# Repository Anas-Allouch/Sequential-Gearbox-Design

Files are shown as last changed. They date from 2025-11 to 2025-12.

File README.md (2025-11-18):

# Sequential Gearbox Design

This project presents the complete design and analysis of a 5-speed sequential gearbox for a rally car.

## Project Scope & Contents

This repository documents the **complete design and analysis process** of a 5-speed sequential gearbox.  
It includes all engineering calculations, modeling, and verification steps based on *Shigley’s Mechanical Engineering Design* and *Le Guide du Dessinateur Industriel (Chevalier)*.

### Main Components & Analyses
- **Gear Design:** module selection, face width, geometry factors, bending and contact stress verification.  
- **Input Shaft Design:** static and fatigue analysis, keyseat and retaining ring groove checks, stress concentration factors.  
- **Output Shaft Design:** torque and moment diagram analysis, critical section evaluation, fatigue and safety factors.  
- **Bearings:** selection, equivalent load calculation, and life estimation.  
- **Keys & Retaining Rings:** dimensioning and verification against shear and crushing.  
- **Housing & Alignment Considerations:** bearing seat fits, shaft shoulders, and axial positioning.  

> The goal is to provide a **complete, transparent, and educational mechanical design example** of a sequential gearbox, from concept to validated dimensions.

## Tools & References

### Software
- **SolidWorks:** 3D modeling of gears, shafts, and gearbox assembly.  
- **MATLAB:** analytical calculations, torque and moment diagrams, fatigue and stress analysis automation.  
- **AutoCAD:** creation of final 2D technical drawings and detailed dimensioning sheets.  
- **Excel:** tabulated design data, safety factor summaries, and calculation sheets.

### References
- *Shigley’s Mechanical Engineering Design* — design methodology, fatigue and stress concentration analysis.  
- *Guide du Dessinateur Industriel (Chevalier)* — dimensional standards, tolerances, and technical drawing practices.  
- *Machinery’s Handbook* — complementary reference for mechanical design data and standard dimensions.

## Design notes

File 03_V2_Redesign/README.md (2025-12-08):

# Abandoning Initial Design (V1)
The first design (V1) was fully modeled and analyzed, but it reached a point where several key issues had no realistic or robust solutions within the existing architecture. Despite multiple refinements, the combination of geometric constraints, stress concentrations, assembly limitations, and interface problems (keys, dogs, shaft transitions, etc.) made it clear that continuing to iterate on the same base layout would not lead to a clean or reliable final design.  
For this reason, the V1 gearbox was OFFICIALLY ditched, and the project is now restarting from a fresh architecture (V2) in order to implement all lessons learned and integrate better design rules from the beginning.

---

# About This Folder (V2)

This folder contains the **new redesign workflow**.
The V2 design is documented through a dedicated Markdown file that records:

- the restart of the architecture
- the sequence of design decisions
- intermediate sketches and reasoning
- constraints and fixes applied
- and how the new gearbox layout evolves step by step

This approach keeps the development traceable and transparent until the final consolidated report is produced.

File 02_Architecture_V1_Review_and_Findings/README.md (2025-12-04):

# Architecture V1 - Review and Findings
This folder documents the **first complete gearbox architecture** of the project, including:
- Input shaft
- Output shaft
- Full set of SolidWorks gearbox parts used in V1
- The complete V1 gearbox assembly
- Initial dog–gear engagement concept
- Notes and explanations of the limitations discovered in this version

During the evaluation of this version, several **critical limitations** were identified.
These limitations led to the upcoming redesign.

### **01_Shafts_Drawings/**
Contains the exported shapes/representations of:
- **Input shaft**
- **Output shaft**

These are not final technical drawings, but the **geometric form and layout** of the shafts as designed in Architecture V1.
They are included here to document the original shaft concepts before the redesign and to allow easy comparison with V2 once all dimensions and calculations are finalized.

### **02_Gearbox_Parts/**
Contains all SolidWorks **individual gearbox components** used in V1:
- Output shaft
- Input shaft
- Gears
- Dog rings
- Keys
- Bearings

This allows reconstruction of the complete V1 assembly for reference.

### **03_Gearbox_Assembly/**
Contains the **Architecture V1 gearbox assembly**.

This assembly was created to:
- Visualize the overall concept  
- Check the positioning of gears, shafts, and dog rings  
- Verify clearances and relative spacing  
- Validate how the parts interact in 3D  
- Identify problems or design conflicts that were not obvious during individual part modeling  

Although this assembly contains limitations that led to the redesign, it is preserved here to document the initial idea and to compare it later with the improved V2 architecture.
In addition to verifying geometry, this assembly was also created to **step away from pure numbers and calculations** and actually build the concept in CAD, helping reveal issues that were not obvious on paper.

### **04_MATLAB/**
Contains the MATLAB work used during the Architecture V1 review.
#### **modified_scripts/**
#### **new_scripts/**

### **05_Safety_Factors_V1/**
Contains a table representing the safety factors that were calculated and resulted in a failed design.
It does not contain the equations and calculation details, but the results and some dimensions used.
it shows the failure points and some notes.

## Summary of V1 Findings

### **Key issues identified:**

1. **Output shaft keyseat depth too large** (7 mm on Ø50 mm shaft)  
   This leads to excessive radius removal → high Kt → fatigue risk

2. **Keyseat placed too close to a shoulder / critical section**  
   This creats a combination of stress concentrations (shoulder + keyseat) that severely weakens the shaft in bending and torsion

3. **Key failure risk on the output shaft**  
   Safety factors were only around **1.0–1.1** in shear and crushing, while the target is **1.5+**
   This makes the keyed dog-hub connection unacceptable on the high-torque output shaft, especially on the first gear

4. **Splines not feasible due to assembly and bearing constraints**  
   Needle bearings and stepped diameters prevent placing splines in the required locations
   Splines cannot be added “anywhere” making a splined dog hub impossible in this current version

5. **Dog ring requires a splined zone to slide axially**  
   For proper engagement into dog pockets, the dog ring must slide along a spline
   The V1 architecture did not provide any feasible spline region for this movement, blocking correct dog operation

## What I Learned
- Critical shaft features must always be checked for **combined stress concentrations**, especially when multiple geometric changes (shoulders, keyseats, grooves) are close together
- Dog hubs require careful balance between key depth, shaft diameter, and torque levels
- Needle bearings strongly restrict where splines can be placed
- Manufacturing feasibility and assembly constraints must always be checked throughout the design
- Initial designs rarely work perfectly — redesign is normal and often unavoidable

## Technical Skills Gained
- Involute gear tooth design
- Spline calculation and spline design
- Real dog-clutch concept understanding (engagement, load transfer, geometry)
- Designing all gearbox parts in SolidWorks (full parts + complete V1 assembly)

## Why I Made This Folder
- To document the first complete gearbox architecture (V1), even though the design ultimately proved unviable
- To clearly show the full concept assembly and the work completed before identifying its limitations
- To demonstrate my SolidWorks modeling skills through fully created parts and assemblies
- To validate the design visually in 3D and step beyond purely analytical calculations
- To identify problems that are not visible in numerical analysis alone, such as assembly feasibility, mounting constraints, and geometric conflicts
- To keep a transparent record of the shortcomings discovered in Architecture V1 before transitioning to a corrected and improved design

## Next Step
- Begin redesigning the output shaft to address the keyseat, stress concentration, and assembly issues identified in V1
- Rebuild the dog-hub interface with improved geometry and safer torque transmission
- Ensure that the new design achieves the desired safety factors (≥ 1.5) for all torque-transmitting features
- Validate whether modifying only the output shaft is sufficient to resolve the limitations
- If required, extend the redesign to include both the input and output shafts
- Integrate all lessons learned from V1 regarding splines, keys, dog engagement, manufacturability, and assembly feasibility
- Develop Architecture V2 as a corrected and more robust version of the gearbox design

## Important Note
Regarding the equations used, simplifications, asumptions and all details, they won't be shown until the final report is done.
This report will be done once everything is checked, and the design is acceptable, meaning no failure at at any point in the whole gearbox.

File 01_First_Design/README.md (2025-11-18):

# First Acceptable Design

This folder contains the first **acceptable and technically coherent**
design of the sequential gearbox project. It was created after multiple 
early design attempts that revealed significant issues, missing
information, or incorrect assumptions. These early failures were essential
for building a solid understanding of the constraints and requirements of
a real multi-speed gearbox.

Throughout the process, I encountered and learned numerous new concepts
related to gearbox engineering that do not appear in simple single-stage
reducers. Topics such as gear load distribution, shaft fatigue under
combined loading, bearing life calculations, and moment/torque diagrams 
were progressively integrated and refined as I
identified mistakes in previous versions.

This directory therefore serves as:
- a **checkpoint** for the first design that no longer contains major
  conceptual errors or unrealistic assumptions, and  
- a **trace of my progress**, documenting how the project evolved from
  failed early designs into a structured, technically valid gearbox
  model.

## Notes on Excel Tables

The Excel files in `02_Excel_Calculations` are **raw engineering 
worksheets**, not formatted reports. They store:
- intermediate values used by MATLAB scripts,
- extracted forces and geometries,
- safety factors calculated using MATLAB,
- and other working data.

Their purpose is to support calculations, not to present final, polished
tables. Clean, validated versions of these data sets will be produced in a
later stage once the full design is refined.

## Notes on CAD Models
SolidWorks part models and technical drawings are **not yet finalized**.
They will be developed once all dimensions, stresses, safety factors, and
design decisions are fully validated. The current `03_Shaft_Drawings`
folder contains only preliminary, non-refined versions of the input and
output shafts. Final CAD models and detailed drawings will be added in a
later design stage.

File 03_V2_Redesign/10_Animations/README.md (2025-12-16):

## Animations
This folder contains short animations of the sequential gearbox.
Each animation shows a single operating case, with one gear engaged at a time.

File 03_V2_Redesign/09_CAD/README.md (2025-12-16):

## CAD Models
Inside solidworks folder, you will find the assemblies, parts and bearings used.  
Two assemblies of the whole gearbox exist:  
- "Sequential_Gearbox": contains the original assembly
- "Sequential_Gearbox_Animation": contains multiple configurations and motion studies. Basically a configuration for each gear engaged alone.

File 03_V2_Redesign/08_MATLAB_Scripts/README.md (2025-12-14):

These MATLAB scripts were developed for preliminary sizing and iterative verification during the design process.  
They are not final or production-level scripts and may be refined or replaced in later design stages.

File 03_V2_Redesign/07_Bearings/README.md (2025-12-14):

# Bearings – Selection and Life Check

Bearings are selected and verified based on required life, reliability, and operating
loads. Life calculations follow standard rolling bearing theory.

---

## Design Targets

- Bearing life: L10,req = 667 hours  
- Reliability: R = 90 %
- Shaft speed range: 4000 rpm for all gears  
- Bearing type: Cylindrical roller bearings  

---

## Load Definition

Bearing loads depend on the engaged gear and transmitted torque.
Each gear produces a different bearing load.

---

## Time Fraction Method

Bearing life is evaluated using a duty cycle approach.

For each gear i:
- Time fraction: t_i  
- Equivalent bearing load: P_i
- Average Rotation Speed: n_avg,i

A global equivalent load is calculated using:

P_eq = [ Σ (t_i * P_i^p *n_avg,i) / (Σ (t_i * n_avg,i) ]^(1/p)

where: 
- p = 10/3 (cylindrical roller bearings)

---

## Results
After calucaltion, I got:
 - input shaft: C10 = 43.788 KN
 - output shaft: C10 = 38.215 KN

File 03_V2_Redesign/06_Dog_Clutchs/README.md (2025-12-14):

## Dog Clutch Failure Checks

Dog clutches are checked against crushing failure of the dog faces and shear failure of the dogs.
Torque transmission is assumed to occur through face contact between engaged dogs.

---

### 1. Tangential Force at Dog Radius

The transmitted torque T produces a tangential force at the mean dog radius:

Ft = T / r_m

where r_m is the mean radius of the dog engagement.

---

### 2. Crushing Failure of Dog Faces

The average bearing (crushing) stress on the engaged dog faces is:

σ_c = Ft / (N_e * A_d)

where:
- A_d is contact area of one dog  
- N_e is the effective number of dogs carrying load

The crushing safety factor is:

n_crushing = σ_c,allow / σ_c

where:
 - σ_c,allow = 0.6 * S_y  

---

### 3. Shear Failure of Dogs

Each dog is also checked in shear at its root section.

The average shear stress in one dog is:

τ = Ft / (N_e * A_s)

where:
- A_s is the shear area of one dog (root cross-section)

The shear safety factor is:

n_shear = τ_allow / τ

where:
 - τ_allow = 0.3 * S_y  

---

### Assumptions

- Load is shared by a limited number of dogs due to manufacturing tolerances  
- Contact pressure is uniformly distributed over the engaged dog faces  
- Dynamic and impact effects during engagement are neglected  
- Dogs are fully engaged during torque transmission  
- Material yield governs failure (fatigue not considered here)

---

### Notes

- Dog clutches are primarily torque-locking elements, not synchronizing devices  
- Impact loads during shifting can govern design in high-speed applications  
- Face width and dog count strongly influence durability and engagement quality

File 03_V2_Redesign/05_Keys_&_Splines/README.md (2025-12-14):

## Key Safety Factor Checks
When dealing with keys, there are 2 types of failures: failure by shear, and failure by crushing.  
Since im using custom made keys, and not using the same key everywhere, safety factor check is required at every key location.  
In the following, i will show the formulas used to calculate these safety factors:  

### 1. Shear Failure Check

The transmitted torque T produces a tangential force on the key:

Ft = 2 * T / d

The average shear stress in the key is:

τ = Ft / (b * l)  

with b: key width;  
     l: key length

The shear safety factor is:

n_shear = τ_allow / τ  

τ_allow = 0.3 * S_y  

where the allowable shear stress is taken from the key material yield strength.

---

### 2. Crushing Failure Check

The same tangential force produces a bearing pressure between the key and the hub.

The average crushing stress is:

σ_c = Ft / (h * l)  

with h: contact height between key and shaft, or key and hub ( both must be checked )  

The crushing safety factor is:

n_crushing = σ_c,allow / σ_c  

σ_c,allow = 0.6 * S_y

---

## Spline Failure Checks
Splines are checked against bearing (crushing) failure of the spline teeth.  
Shear of spline teeth is generally not governing and is neglected in standard design practice.  

---

### 1. Tangential Force at Spline Radius

The transmitted torque T produces a tangential force at the spline radius:

Ft = T / r

where r is the pitch circle spline radius.

---

### 2. Crushing Stress on Spline Teeth

The average crushing stress on the loaded spline flanks is:

σ_c = Ft / (N_e * h_e * l)

where the effective number of teeth in contact is:

N_e = 0.3 * N  

And h_e is the height of the tooth ( distance from addendum to dedendum )  

---

### 3. Crushing Safety Factor

The crushing safety factor is defined as:

n_crushing = σ_c,allow / σ_c  

σ_c,allow = 0.6 * S_y  

where the allowable crushing stress is based on the yield strength of the weaker material  
(shaft spline or hub spline).

---

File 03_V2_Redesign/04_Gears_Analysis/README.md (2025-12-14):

# Gears Analysis
Based on Shigley ways and AGMA standards, there are 2 types of failures that can occur in gears: failure by bending, and failure by wear ( or contact ).  
In this folder, you will find a table showing the safety factor for each case, for every gear in the gearbox.  
As always, assumptions and constants are going to be mentioned in the final project report.  

Values are calculated with the MATLAB code that can be found in its corresponding folder.

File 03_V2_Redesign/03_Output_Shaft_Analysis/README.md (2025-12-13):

For the output shaft analysis, we will be using the same moment diagrams used for input shaft.  
The reason why I let myself do that is because the axial positions of gears, where forces are applied, is the same as on the input shaft.  
The difference is that the forces are in the opposite direction shown on the input shaft, excluding reverse gear.  
The real moments diagrams on the output shaft are flipped in comparison to input shaft diagrams, but the absolute value of moments is always the same, so technically we can use the same moment diagrams cause it will not affect calculations.  
So each pair of gears, I took the one that is more critical and gives higher moment values and I calculated the safety factors based on it. 
These pairs are grouped like the following:  
 - Reverse gear with gear 1  
 - Gear 2 with gear 3  
 - Gear 4 with gear 5  

So for the first pair, I used the gear 1 moment diagrams. For second pair, I used the gear 2 moment diagrams. For the third pair, I used the gear 4 moment diagrams.  
And each pair has a dog clutch mecanisme between them.

Same as input shaft, an excel table includes all safety factors of different shaft fatigue analysis criterias.

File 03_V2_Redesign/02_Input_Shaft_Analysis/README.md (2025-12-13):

This folder presents input shaft analysis. From free body diagram, to moment diagrams for each case that we have, to finally fatigue analysis.  
Regarding fatigue analysis, I used all 4 different criterias that Shigley had in his book. However, the important safety factor that I will be using as my reference
safety factor is Goodman.  
In some places, ASME elliptic criteria might produce low values, and that's completely normal when the moment values at that location are low. And that weird behavior is one of the reasons why Goodman is the criteria to follow since it is conservative in all cases.  
The calculations and formulas details will not be shown until the final polished report.  
An excel table in "Shaft_Analysis" folder contains the different safety factors at each shaft feature ( shoulders, grooves, keyways, ... )  

Calculations were done with the help of the matlab code that can be found in 08_MATLAB_Scripts in its dedicated folder.

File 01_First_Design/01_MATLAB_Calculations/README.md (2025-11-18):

# MATLAB Calculations (Initial Design Phase)

This directory contains the MATLAB modules used during the first design
of the sequential gearbox project. Each sub-folder corresponds
to a specific analysis task (gear forces, moment diagrams, shaft stresses, etc.).

The scripts and functions here are **not optimized** and **not intended
for production-level code**. Their purpose is only to automate repetitive
engineering calculations and avoid doing them manually in Excel.

## Structure
Each module folder contains:
- A main script (`*_main.m`) that runs the calculation.
- Local helper functions used by that module.
- Path setup at the top of every script to correctly access Excel data
  stored in `02_Excel_Tables`.

## Notes
- All paths to Excel files are handled dynamically using
  `mfilename('fullpath')` to ensure compatibility on any computer or
  GitHub clone.
- No global code organization or optimization has been applied yet.
- A future “clean code” pass will reorganize, optimize, and document the
  final version of the computational tools.

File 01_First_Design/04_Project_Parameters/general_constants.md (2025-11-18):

# General Design Constants

## Gear Geometry

- **Gear type:** Spur gears  
- **Module:** 3.5 mm/tooth
- **Face width, b:** 35 mm  
- **Pressure angle, α:** 20°  

These values are taken as fixed for all gears in this first design 
and are used consistently in gear, shaft, and bearing calculations.

## Components

- **Keys:**  
  - Custom dimensions (non-standard).  
  - Sized specifically for the shaft diameters and torque levels in this
    gearbox rather than using catalog key sizes.

- **Bearings:**  
  - Standard catalog bearings are used.  
  - Selection is based on load capacity and life (L10) according to
    manufacturer data.

- **Retaining rings:**  
  - Standard (catalog) retaining rings.  
  - Grooves and shoulder details follow standard recommendations for
    the chosen ring series.

## Design Scope

These constants define the baseline configuration for the first complete
acceptable gearbox design. Any change to module, face width, pressure
angle, or component standardization would require a global redesign of
gears, shafts, and associated components.

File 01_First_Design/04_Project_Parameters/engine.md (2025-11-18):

# Engine and Input Torque Assumptions

## Intended Application

The gearbox is not designed for a specific competition homologated rally car,
but for a **rally-style/off-road oriented car** built with high torque and
good drivability in mind. The goal is to size a sequential gearbox capable of
handling realistic loads for a powerful off-road/rally-style vehicle, without
being tied to an exact commercial engine model.

## Engine Performance Assumptions

For the purposes of gearbox design, the engine is assumed to deliver:

- **Peak torque:** ≈ 450 Nm  
- **Peak power:** ≈ 350 hp  

These values are representative of a highly tuned turbocharged engine
(4- or 6-cylinder) where:
- Maximum torque (~450 Nm) occurs at mid-range rpm, and  
- Maximum power (~350 hp) is reached at higher rpm.

Only the **torque** is directly used for gearbox sizing. Power is mainly
indicative, to ensure the chosen torque level is consistent with a realistic
engine configuration.

## Use in the Design

In this first design:
- The **450 Nm** torque level is taken as the reference **maximum engine
  torque at gearbox input** (before gear ratios).
- Safety factors, overload factors, and dynamic effects are handled in the
  subsequent gear, shaft, and bearing calculations, based on this input
  torque level.

A more detailed engine torque curve (torque vs rpm) may be introduced in a
later refinement stage if needed, but for now the design is based on this
single worst-case torque value.

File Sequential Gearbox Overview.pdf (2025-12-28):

Author: Anas ALLOUCH

## Sequential Gearbox

## Project Concept and Objectives

This project focuses on the complete mechanical design of a 5-speed sequential gearbox, developed as a self-driven engineering effort with the intention of approaching a realistic and manufacturable solution rather than a purely academic exercise. The gearbox architecture is based on dog-ring engagement mechanism, a configuration commonly found in high-performance and motorsport applications. A mechanism that operates through purely mechanical means.
Unlike conventional gear reducers or speed multipliers, which operate under fixed and well-defined conditions, a sequential gearbox inherently combines multiple operating cases within a single design. Each gear engagement represents a distinct load path and loading condition, affecting gears, shafts, bearings, splines, keys, and engagement components differently. A central challenge of this project was therefore to identify the most critical cases while ensuring overall coherence and consistency across the entire drivetrain.
The design was approached with a strong emphasis on classical mechanical engineering principles and established design standards. Component sizing and verification were performed using analytical methods drawn from machine design theory, bearing catalogs, and international standards, with careful attention paid to the assumptions underlying each calculation, their validity, and their impact on the final results.
Beyond obtaining numerical safety factors, the project aimed to develop a deeper understanding of how real mechanical systems are designed, including the need for iteration, trade-offs, and refinement. Multiple intermediate concepts and configurations were evaluated and ditched before obtaining the final design.

## Main Objectives

- Design a complete and coherent sequential gearbox architecture
- Integrate gears, shafts, bearings, splines, keys, and dog clutches into a single functional system
- Apply classical mechanical design theory to verify critical components
- Develop a design that serves as a basis for further tests and verification, taking it from analytical to experimental validation

L | L
K | K

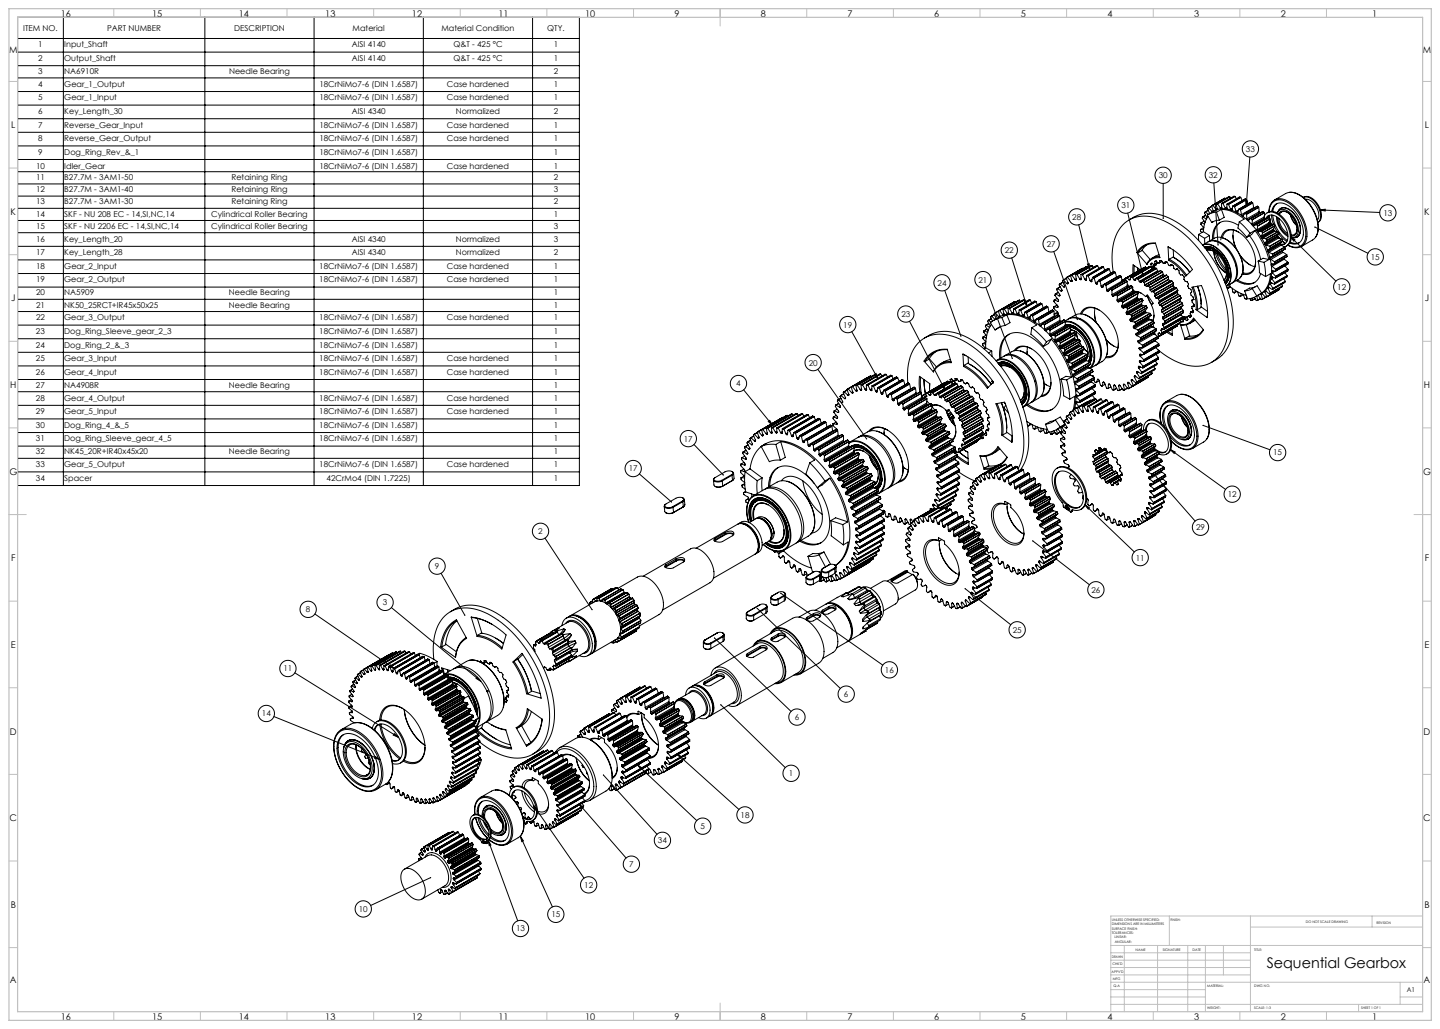
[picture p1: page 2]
ITEM NO.; PART NUMBER; DESCRIPTION; Material; Material Condition; QTY.; Input_Shaft; AISI 4140; Output_Shaft; Needle Bearing; Gear_1_Output; 18CrNiMo7-6 (DIN 1.6587); Case hardened; Gear_1_Input; Key_Length_30; AISI 4340; Normalized; Reverse_Gear_Input; Reverse_Gear_Output; Dog_Ring_Rev_&_1; Idler_Gear; Retaining Ring; SKF - NU 208 EC - 14,SI,NC,14; Cylindrical Roller Bearing; SKF - NU 2206 EC - 14,SI,NC,14; Key_Length_20; Key_Length_28; Gear_2_Input; Gear_2_Output; NK50_25RCT+IR45x50x25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

UNLESS OTHERWISE SPECIFIED:
DIMENSIONS ARE IN MILLIMETERS
SURFACE FINISH:
TOLERANCES:
LINEAR:
ANGULAR:

NAME | SIGNATURE | DATE | | | TITLE: Sequential Gearbox

DRAWN
CHK'D
APPV'D
MFG
Q.A | | | | MATERIAL: | DWG NO. | A1

## Verification and Engineering Work

The mechanical design of the sequential gearbox was verified using classical machine design methods and established engineering references. Gear geometry and strength were evaluated using AGMA-based criteria to ensure adequate resistance to bending and contact stresses under the most critical operating conditions.
Shafts were dimensioned and verified under combined torsional and bending loads. Stress concentration effects and fatigue behavior were evaluated using standard failure criteria as presented in Shigley’s Mechanical Engineering Design, allowing identification of governing sections and critical load cases.
Bearing selection was performed using the Shigley bearing life methodology, based on duty-cycle-dependent equivalent dynamic loads. Bearings were selected from manufacturer catalogs such that their basic dynamic load ratings exceed the calculated equivalent loads.
Torque transmission elements, including keys, splines, and dog clutches, were verified against their governing failure modes using classical strength-of-materials approaches. Keys were checked in shear and crushing, splines were verified in bearing pressure following standard practice, and dog clutches were evaluated for crushing and shear of the dog teeth.
The final design is the result of multiple iterations, during which several intermediate configurations were evaluated and refined. This process highlights the iterative nature of engineering design, where minor adjustments can sometimes resolve identified issues, while in other cases a more substantial redesign is required to achieve a satisfactory solution.

## What I Learned

This project provided a comprehensive learning experience in mechanical design, extending beyond isolated calculations to the development of a complete and coherent drivetrain system. One of the most significant lessons was learning how to define, justify, and apply engineering assumptions. Understanding when simplifications are valid, how they influence results, and how to interpret safety factors in context proved to be as important as the calculations themselves.
From a technical perspective, the project deepened my understanding of drivetrain components and their interaction within a complex mechanical system. Designing a sequential gearbox required integrating gears, shafts, bearings, splines, keys, and dog clutches into a single architecture, while accounting for multiple operating cases and distinct load paths. This differs fundamentally from the design of fixed-ratio reducers, where operating conditions are more limited and uniform.
In addition to technical knowledge, this work strengthened practical engineering skills related to design iteration and problem-solving. Several intermediate design concepts were analyzed and discarded as new constraints emerged, leading to progressive refinement of the gearbox layout and component sizing. This iterative process highlighted the non-linear nature of real engineering design.
From a software perspective, the project improved proficiency in CAD modeling, assembly management, and technical drawing preparation, as well as in the organization and documentation of complex engineering work. Structuring calculations, design choices, and results in a clear and traceable manner was a key outcome of the project.
Overall, this project reinforced the difference between theoretical coursework and practical mechanical design, providing a realistic view of the engineering process and significantly deepening both technical understanding and engineering judgment.

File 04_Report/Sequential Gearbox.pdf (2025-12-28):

## Engineering Design Study

## Sequential Gearbox

Mechanical Design Report
Personal Engineering Project

Author: Anas ALLOUCH

## Contents

1 Introduction | 4
2 Technical Specifications | 5
3 Gearbox Architecture and Layout | 7
4 Shaft Design and Verification | 9
5 Gears Analysis | 20
6 Keys | 24
7 Splines | 26

8 Bearings | 27
9 Engagement Mechanism | 29
10 Design Summary | 33
11 Design Assumptions and Limitations | 33
12 Supporting Material | 33
13 Conclusion | 34

## List of Tables

1 | Gear specifications and ratios | | 5
2 | Vehicle speed and wheel torque at redline (neng = 6500 rpm) | | 6
3 | Assumed time fraction per forward gear | | 6
4 | Summary of materials used for main gearbox components | | 7
5 | Bending moments and torsional loading at critical shaft features – Gear 1 engaged – input shaft . 14
6 | Bending moments and torsional loading at critical shaft features – Gear 1 engaged – output shaft 14
7 | Theoretical stress concentration factors for the input shaft | 18
8 | Theoretical stress concentration factors for the output shaft | 18
9 | Fatigue safety factors for the input shaft – Gear 1 engaged | 19
10 | Fatigue safety factors for the output shaft – Gear 1 load case | 19
11 | Summary of Gears Safety Factors | 24
12 | Safety Factors of Keyed Connections | 25
13 | Crushing Safety Factors of Spline Connections | 27
14 | Needle Bearings Used for Gear Support | 29
15 | Dog Ring Geometry and Safety Factors | 32

## 1 Introduction

### 1.1 Project Context

This project consists of the mechanical design and verification of a sequential gearbox intended for high-torque automotive applications, with a particular focus on off-road and rally-type operating conditions. The work focuses on the dimensioning and validation of the main mechanical components, including shafts, gears, torque transmission elements, and bearings, under realistic loading conditions. The gearbox is designed using standard engineering methods and established design references, with an emphasis on structural integrity, fatigue resistance, and mechanical reliability. Computer-aided design tools are used to define the geometry and assembly of the system, while analytical calculations are employed to assess stresses, safety factors, and component life. The objective of the project is to develop a gearbox design representative of real-world engineering practice.

### 1.2 Motivation

The idea behind this project is to apply mechanical engineering design methods to a complete drivetrain subsystem rather than to isolated components. Sequential gearboxes involve the interaction of shafts, gears, bearings, and torque transmission elements under combined loading and fatigue conditions, making them a relevant case study for power transmission design. They are known for their purely mechanical mechanism. This project aims to bridge the gap between academic theory and practical engineering by using recognized design standards, realistic load cases, and iterative dimensioning to develop a coherent and mechanically robust gearbox concept.

### 1.3 Design Objectives

The primary objectives of the sequential gearbox design are summarized as follows:
- Safely transmit the specified engine torque under high-load operating conditions, including shock loading representative of off-road and rally-type use.
- Ensure adequate fatigue life for all rotating and torque-transmitting components over the intended service life.
- Achieve reliable sequential gear engagement through mechanically robust engagement elements.
- Use realistic materials, heat treatments, and manufacturing constraints consistent with industrial practice.
- Apply recognized mechanical design standards and references for stress, fatigue, and life verification.
- Maintain a compact and mechanically coherent layout suitable for automotive integration.
- Focus on the development of a technically realistic design, rather than weight minimization, conceptual novelty, or performance optimization beyond standard engineering practice.

## 2 Technical Specifications

### 2.1 Engine Torque and Speed Range

The gearbox is designed to operate with an internal combustion engine delivering high torque at relatively moderate rotational speeds, representative of off-road and rally-type automotive applications. The design calculations are based on a nominal peak engine torque of

Teng = 450 N·m

with an engine speed range extending up to a redline speed of

nred = 6500 rpm

These values are used as reference inputs for the dimensioning of shafts, gears, bearings, and torque transmission elements, ensuring adequate strength and fatigue resistance under the most demanding operating conditions.

### 2.2 Gear Set and Ratios

The selected gear pairs were obtained after multiple iterations to satisfy the targeted ratio spread and a constant center distance constraint for the forward gears. The final gear data are summarized in Table 1. A dedicated layout is used for the reverse gear train to satisfy the center distance requirement without collinearity of the input, idler, and output gears.

Table 1: Gear specifications and ratios
Gear | Module zin | zout | Ratio igear | Center distance [mm]
1 | 3.0 | 25 | 63 | 2.52 | 132
2 | 3.0 | 31 | 57 | 1.8387 | 132
3 | 3.0 | 37 | 51 | 1.378 | 132
4 | 3.0 | 41 | 47 | 1.1463 | 132
5 | 3.0 | 49 | 39 | 0.7959 | 132
Reverse | 2.5 | 31 | 68 | 2.1935 | 132
Idler | 2.5 | 23 | – | – | –

### 2.3 Assumptions for Speed and Wheel Torque

To evaluate vehicle speed and wheel torque across gears, the following assumptions are used:
- Final drive (differential) ratio: i

final = 4.8
- Differential efficiency: ηfinal = 0.9
- Tire size: 225/40 R18, resulting in an approximate tire diameter D ≈ 0.6372 m and circumference Ctire ≈ 2.0 m

### 2.4 Speed and Torque Across Gears

Wheel speed and vehicle speed at engine speed neng are computed using:

nwheel =

neng
igear i
final

, v =

nwheel Ctire 60
1000

,

where v is expressed in km/h when nwheel is in rpm and Ctire in meters. The gearbox output torque and wheel torque are computed as:
Tout = Teng igear, Twheel = Teng igear i

final ηfinal.
Using Teng = 450 N ⋅ m and neng = nred = 6500 rpm, the results are summarized in Table 2.

Table 2: Vehicle speed and wheel torque at redline (neng = 6500 rpm). Gear Speed [km/h] Wheel torque Twheel [N⋅m]
1 | 64.54 | 4898.88
2 | 88.46 | 3574.43
3 | 118.03 | 2678.83
4 | 141.89 | 2228.41
5 | 204.36 | 1547.23

The values obtained are considered acceptable for the intended application. The design focus is not maximum top speed, but rather mid-range drivability, torque availability, and acceleration under severe operating conditions.

### 2.5 Reference Service Life and Operating Assumptions

For the purpose of the gearbox design and subsequent mechanical verification, a reference service life and representative operating conditions are defined. These assumptions are used consistently throughout the shaft, gear, and bearing calculations.
The target service life of the gearbox is set to

Lkm = 40 000 km.

Assuming an average vehicle speed of
| vavg = 60 km/h,
the corresponding operating life in hours is
| Lℎ =

40 000
60
| | ≈ 667 h.

A mixed usage profile is assumed, combining aggressive off-road driving, rally-type operation, and normal cruising. The distribution of operating time across the forward gears is represented by the time fractions listed in Table 3. These values are used later to define representative loading and duty cycles.

Table 3: Assumed time fraction per forward gear.
| Gear | Time fraction
Gear 1 | 0.10
Gear 2 | 0.20
Gear 3 | 0.20
Gear 4 | 0.25
Gear 5 | 0.25

### 2.6 Materials Summary

The materials selected for the main gearbox components are summarized in Table 4. Detailed justification and verification are provided in the corresponding design sections.

Table 4: Summary of materials used for main gearbox components.
Component | Material
Shafts | AISI 4140 (Q&T at 425 ∘C)
Gears | 18CrNiMo7-6 (case-hardened)
Dog Rings | 18CrNiMo7-6
Keys | AISI 4340 (Normalized)

## 3 Gearbox Architecture and Layout

This section describes the overall architecture of the sequential gearbox and the main constraints that governed its layout. The objective is to present the structural organization of the transmission and the interaction between its main components prior to detailed mechanical verification.

### 3.1 Sequential Gearbox Concept

The gearbox follows a sequential shifting concept, where gears are engaged in a fixed order through axial movement of engagement elements called ”dog rings”. Gear selection is performed step-by-step, without the possibility of directly skipping gears. This architecture is well suited for applications requiring rapid and robust gear changes under high load conditions, such as off-road and rally-type use.

### 3.2 Shaft Arrangement

The gearbox architecture is based on an input shaft and an output shaft, with gear pairs arranged to achieve the required transmission ratios. Forward gears are laid out to maintain a constant center distance, simplifying shaft geometry and bearing arrangement. The output gears are designed to rotate freely on the output shaft and are selectively engaged through dedicated engagement elements, allowing individual gear selection without permanent coupling.

### 3.3 Gear Ratio Selection Constraints

The selection of the gear ratios was driven by multiple constraints, including the desired ratio spread, acceptable vehicle speeds, torque availability across gears, and geometric limitations imposed by a fixed center distance. Additional constraints included the use of standard gear modules, realistic tooth counts, and compatibility with the chosen shaft layout, as well as ensuring even wear across all gear teeth. Several candidate gear sets were evaluated, and the final configuration was retained based on its ability to satisfy these constraints while maintaining a mechanically coherent architecture.

### 3.3.1 Gear Ratio and Center Distance Logic

The transmission ratio of each gear pair is defined by the ratio of the number of teeth of the output gear to that of the input gear,
| igear = zout
| zin .

For a given gear module m, the pitch diameter of a gear is directly proportional to its number of teeth,
| d = m z.
The center distance between the input and output shafts is equal to the sum of the pitch radii of the mating gears and can be expressed as
a =

din + dout
| 2 = m
| 2 (zin + zout).
By expressing the number of teeth of the output gear as a function of the transmission ratio,
| zout = igear zin,
the center distance relation becomes
| a = m
| 2 zin (1 + igear) .
The gear set selection was initiated with the first gear, which was sized to achieve the desired gearbox output torque range of approximately 1300–1500 N ⋅ m to obtain the desired torque at wheel value, while maintaining realistic tooth counts and standard gear modules. The center distance was fixed based on the first gear.

Using the obtained center distance relation, the gear selection procedure consists of choosing a target transmission ratio and determining an admissible number of teeth for the input gear. The corresponding number of teeth of the output gear is then calculated from the ratio relation.
The resulting tooth numbers are checked to ensure integer values, realistic gear proportions, and favorable meshing conditions, in particular by avoiding common divisors between the mating gears in order to promote uniform tooth wear.
Once a candidate pair of tooth numbers is obtained, the center distance and the resulting transmission ratio are recomputed to verify consistency. If the geometric and kinematic conditions are satisfied, the gear pair is retained and the procedure is repeated for the next gear.

### 3.4 Reverse Gear Arrangement

Unlike the forward gears, the reverse gear train requires an additional idler gear to invert the direction of rotation. To satisfy the center distance constraint while avoiding co-linearity between the input, output, and idler gears, a dedicated reverse gear layout is implemented. This arrangement allows the reverse gear to meet geometric requirements.
The resulting arrangement is the following:

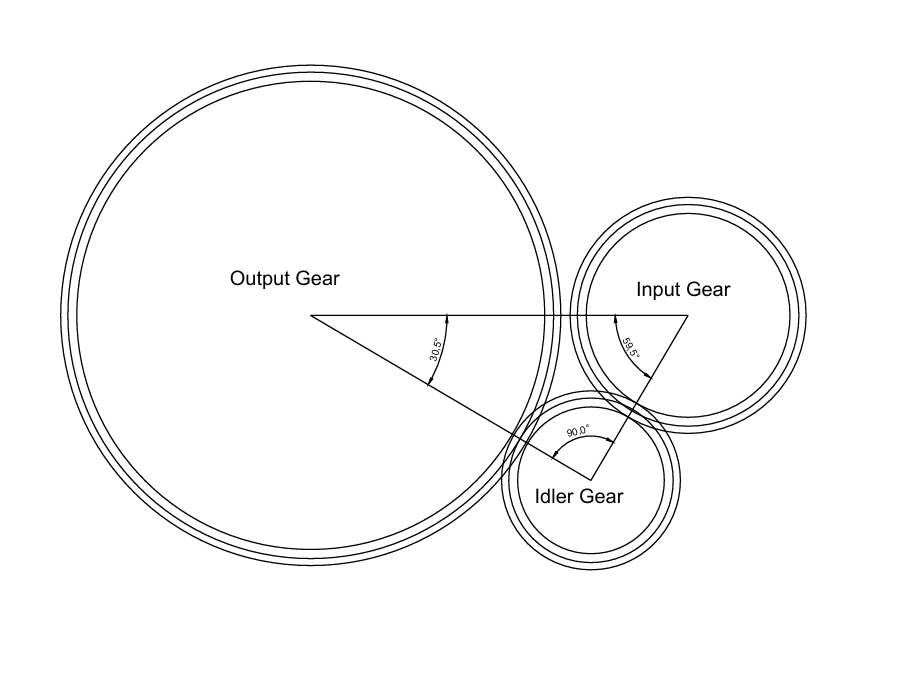
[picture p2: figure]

Figure 1: Reverse gear arrangement with offset idler gear to satisfy the center distance constraint.

The relative positioning of the gears is defined by angle values of 59.5∘

and 30.5∘

## 4 Shaft Design and Verification

### 4.1 Shaft Layout and Geometry Definition

The shaft geometry is defined prior to stress and fatigue verification in order to establish the locations of gears, bearings, and torque transmission elements. This preliminary layout is used to identify critical sections, define load application points, and provide a consistent geometric basis for the analytical calculations presented in the following sections. The geometry presented at this stage corresponds to an initial design intended for verification purposes and does not represent the final manufacturing drawing.
The dimensions in this drawing are used for moment diagrams and all fatigue analysis. The dimensions were chosen based on previous failed designs and they were selected in a way to avoid decimal numbers while always maintaining conservative results.

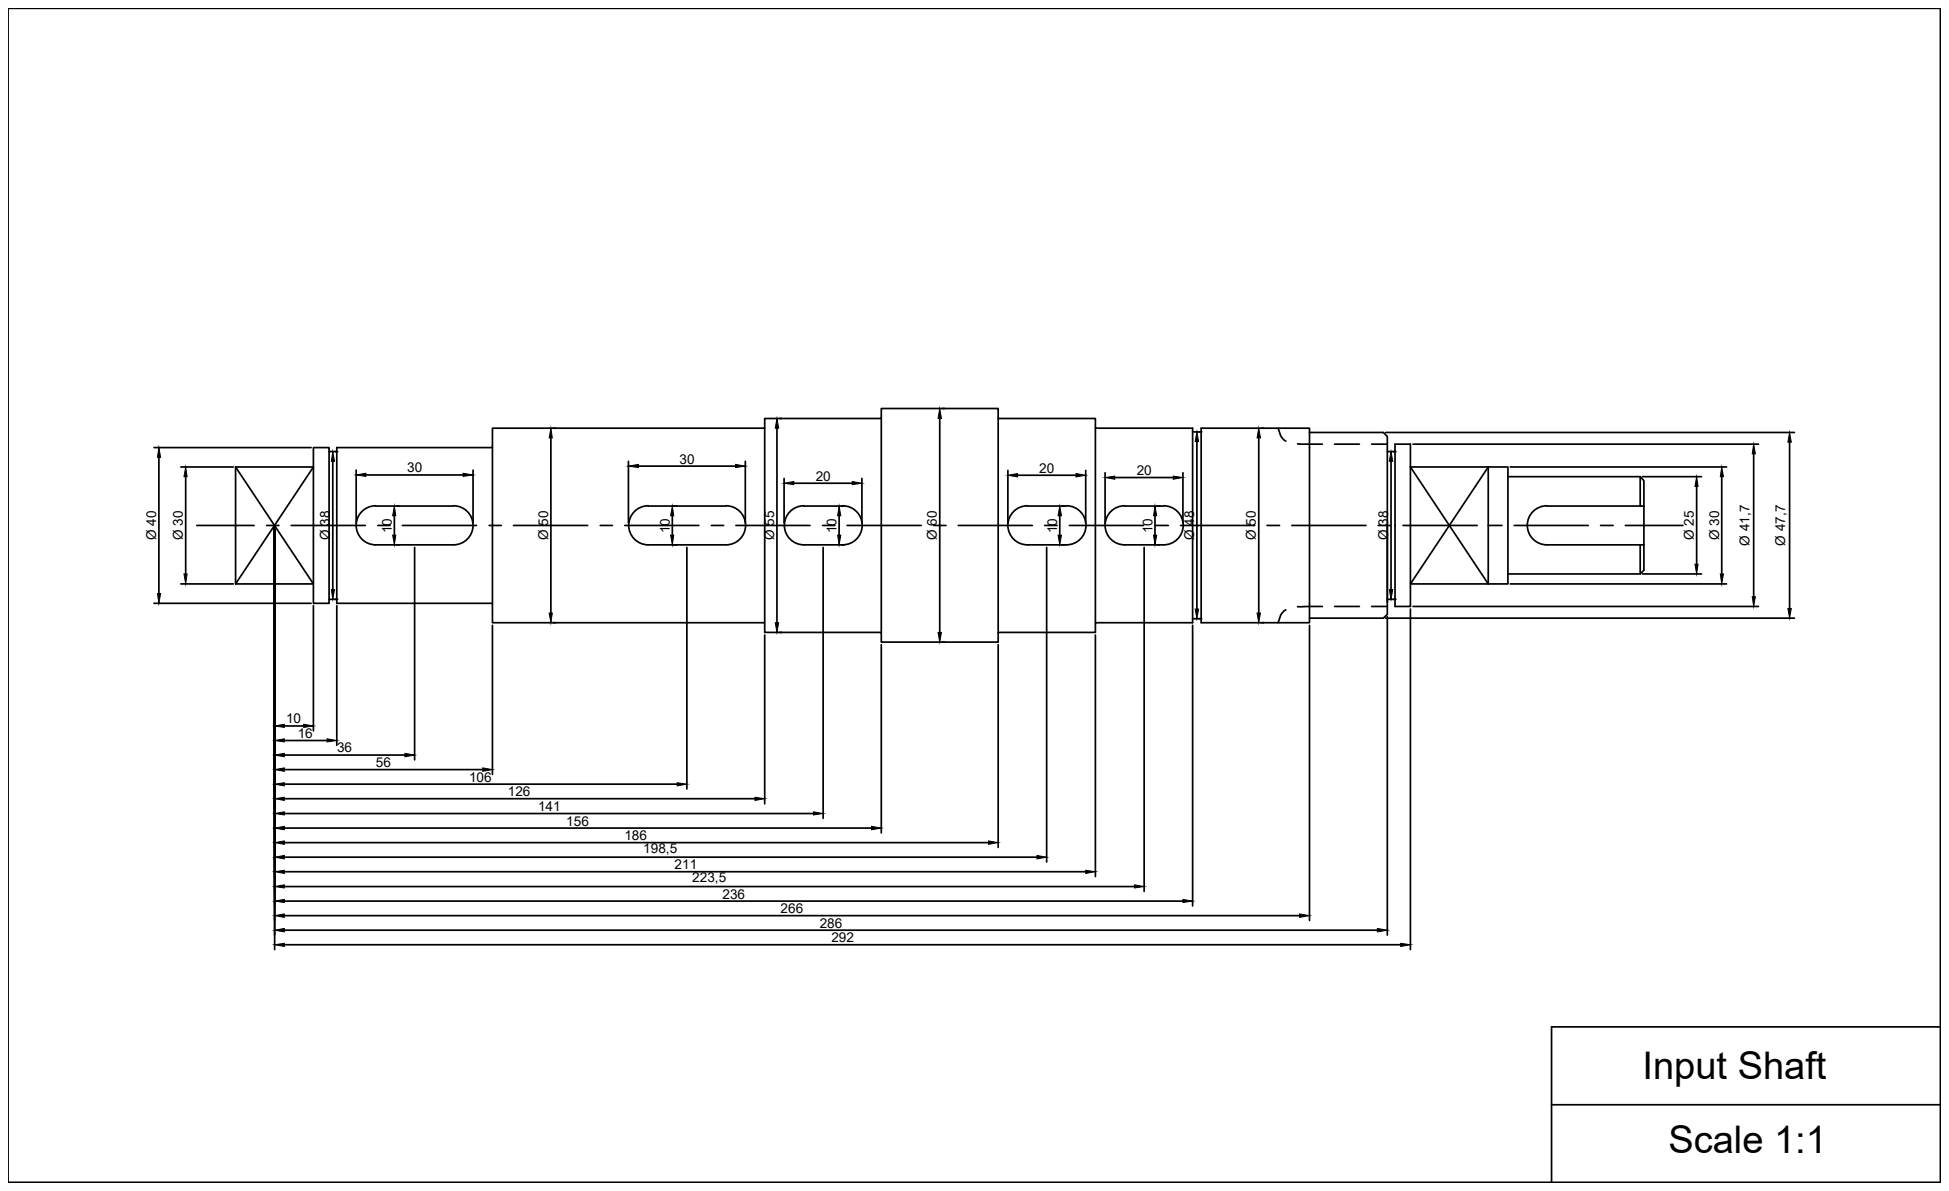
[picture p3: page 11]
Input Shaft; Scale 1:1

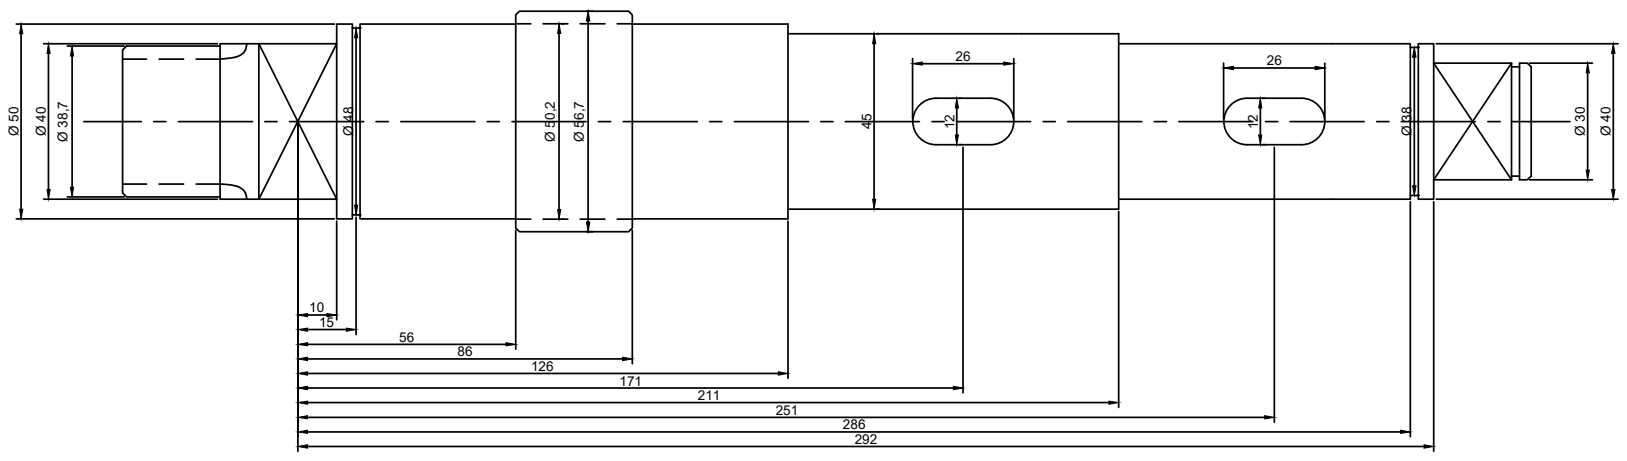
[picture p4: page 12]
Output Shaft; Scale 1:1

### 4.2 Load Cases on Shafts

Due to the sequential nature of the gearbox, only one gear pair is engaged and transmitting torque at any given time. Although all gears are in continuous rotation, torque is transferred exclusively through the engaged gear, while the remaining gears rotate freely without carrying load. Consequently, each gear engagement is treated as an independent load case.
The shaft loading analysis is therefore performed by considering each forward gear and the reverse gear separately. For each load case, the transmitted torque is assumed to be constant along the shaft segment between the input and the engaged gear, while bending loads arise from the radial forces generated at the gear mesh and transmitted to the shaft through the bearings.
For a given gear engagement, the applied loads are defined by:
- The transmitted torque corresponding to the engaged gear ratio.
- The radial gear mesh forces acting at the gear location.
- The reaction forces at the bearing supports.
Free-body diagrams are constructed for each shaft configuration, and the resulting bending moment distributions are obtained. From these, bending moment diagrams are generated in the principal planes, allowing me to obtain the absolute maximum moment at each critical point on the shaft (grooves, shoulder, keyseats, ...) required for shaft fatigue analysis. This procedure is repeated for each gear engagement.
For the output shaft, the same bending moment diagrams obtained for the input shaft are used as a basis for the stress and fatigue analysis. This is justified by the fact that, for each engaged gear, the radial gear mesh forces acting on the two mating gears are equal in magnitude and opposite in direction.
In addition, the axial position of gears and bearings are the same on the input and output shaft. Consequently, the resulting bending loads transmitted to the input and output shafts are identical in magnitude for a given gear engagement.

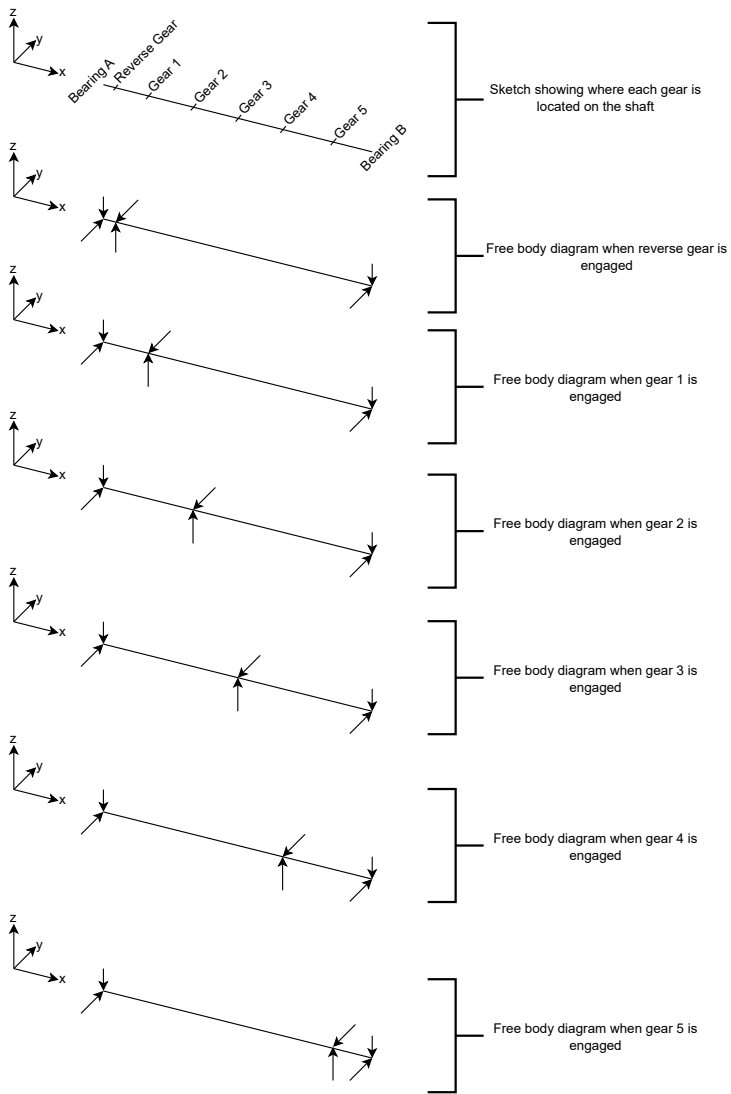
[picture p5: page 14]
Reverse Gear; Gear 1; Gear 2; Gear 3; Gear 4; Gear 5; engaged; Bearing B; Bearing A

Sketch showing where each gear is

located on the shaft

Free body diagram when reverse gear is

Free body diagram when gear 1 is

Free body diagram when gear 2 is

Free body diagram when gear 3 is

Free body diagram when gear 4 is

Free body diagram when gear 5 is

Since the analysis focuses on the magnitude of bending moments and the resulting stress envelopes, the same moment diagrams can be conservatively applied to both shafts. So in practice, the moment diagrams on the output shaft should be in the opposite direction as those on the input. But since I will be using the absolute maximum moment value, the sign of the moment has no effect on results.
Since the gear engagement mechanism deals with 2 gears at a time, I used the moment diagrams for the more critical case between each pair of gears.

### 4.3 Bending Moments and Torsional Loading at Critical Sections

For subsequent stress and fatigue verification, the bending moment and torque values are summarized at a set of predefined critical shaft features (shoulders, bearing seats, grooves, keyseats, and spline locations).
After many attempts at different designs, the most critical case that was controlling the design was when gear 1 is engaged. So for this reason, the values that will be tabulated and shown in this report are going to be for this case, while always providing full results for other cases in the additional documents to this report.

### 4.3.1 Input Shaft

For each feature, the absolute maximum bending moment is calculated, which corresponds to the resultant bending moment magnitude, M = √
M²

x + M²
y

Table 5: Bending moments and torsional loading at critical shaft features – Gear 1 engaged – input shaft
Feature | Location [mm] Mxy [N⋅m] Mxz [N⋅m] Mmax [N⋅m] Tmax [N⋅m]
Shoulder bearing A | 10 | 26.64 | -73.18 | 77.88 | 450
Groove | 15 | 39.96 | -109.78 | 116.82 | 450
Keyseat (reverse gear) | 36 | 95.89 | -263.46 | 280.37 | 450
Shoulder after reverse | 56 | 149.17 | -409.83 | 436.13 | 450
Keyseat gear 1 | 106 | 282.35 | -775.75 | 825.54 | 450
Shoulder after gear 1 | 126 | 253.54 | -696.59 | 741.30 | 450
Keyseat gear 2 | 141 | 231.93 | -637.22 | 678.12 | 450
Shoulder after gear 2 | 156 | 210.32 | -577.85 | 614.94 | 450
Shoulder before gear 3 | 186 | 167.11 | -459.12 | 488.58 | 450
Keyseat gear 3 | 198 | 149.82 | -411.62 | 438.04 | 450
Shoulder after gear 3 | 211 | 131.09 | -360.17 | 383.28 | 450
Keyseat gear 4 | 223 | 113.80 | -312.67 | 332.74 | 450
Groove | 237 | 93.64 | -257.26 | 273.77 | 450
Shoulder before gear 5 | 266 | 51.86 | -142.48 | 151.63 | 450
Groove | 286 | 23.05 | -63.33 | 67.39 | 450
Shoulder bearing B | 292 | 14.41 | -39.58 | 42.12 | 450

### 4.3.2 Output Shaft

Table 6: Bending moments and torsional loading at critical shaft features – Gear 1 engaged – output shaft
Feature | Location [mm] Mxy [Nm] Mxz [Nm] Mmax [Nm] Tmax [Nm]
Shoulder bearing A | 10.00 | 26.64 | -73.18 | 77.88 | 450.00
Groove | 15.00 | 39.96 | -109.78 | 116.82 | 450.00
Shoulder after reverse | 56.00 | 149.17 | -409.83 | 436.13 | 450.00
Shoulder before gear 1 | 86.00 | 229.08 | -629.38 | 669.77 | 450.00
Shoulder after gear 1 | 126.00 | 253.54 | -696.59 | 741.30 | 450.00
Dog sleeve keyseat gear 2–3 | 171.00 | 188.71 | -518.49 | 551.76 | 450.00
Shoulder after gear 3 | 211.00 | 131.09 | -360.17 | 383.28 | 450.00
Dog sleeve keyseat gear 4–5 | 251.00 | 73.47 | -201.85 | 214.81 | 450.00
Groove | 286.00 | 23.05 | -63.33 | 67.39 | 450.00
Shoulder bearing B | 292.00 | 14.41 | -39.58 | 42.12 | 450.00

### 4.4 Shaft Fatigue Analysis

### 4.4.1 Shaft Material

The shafts are assumed to be manufactured from AISI 4140 steel, quenched and tempered at 425 ∘C. The mechanical properties used for the stress and fatigue calculations are summarized below:
- Material: AISI 4140 steel
- Heat treatment: quenched and tempered at 425 ∘C
- Ultimate tensile strength: Sut = 1250 MPa
- Yield strength: Sy = 1140 MPa

### 4.4.2 Alternating and Mid-range Parameters

Before applying fatigue failure criteria, the nature of the bending and torsional loading acting on the gearbox shafts is defined. In the following, the subscripts a and m denote the alternating and midrange components of the applied loads, respectively.
Bending Loading
The bending moments acting on the gearbox shafts are generated by the radial forces arising from gear mesh interactions. These forces are fixed in space, as they are transmitted through the gearbox housing and bearing supports, while the shafts rotate relative to them.
As a consequence, a material point on the shaft experiences a reversal of bending stress every half revolution. From a fatigue perspective, the shaft therefore behaves as a rotating beam subjected to fully reversed bending. Accordingly, the bending moment components are defined as:

Ma = Mmax, Mm = 0,

where Mmax is the resultant bending moment obtained from the bending moment diagrams.
This assumption applies to both the input and output shafts and corresponds to the classical rotating-shaft fatigue model described in standard mechanical design references.
Torsional Loading
Torque is transmitted through gears that are rotationally fixed to the shafts. For the input shaft, torque is supplied by the engine and is always transmitted in the same direction. Although torque fluctuations may occur due to engine firing pulses, the transmitted torque does not reverse sign.
For the output shaft, torque direction may change during acceleration, engine braking, or overrun conditions. However, in the absence of detailed vehicle dynamics and braking torque data, a simplified and consistent assumption is adopted for the present design study.
For both the input and output shafts, the torsional loading is therefore treated as steady torsion, characterized by:
Tm = Tmax, Ta = 0,
where Tmax is the maximum transmitted torque for the considered gear engagement.
This treatment is commonly adopted in gearbox shaft fatigue analyses and is consistent with standard mechanical design practice.
Summary of Fatigue Loading Model
Based on the above considerations, the fatigue analysis of the gearbox shafts is performed using the following loading model:
- Bending (fully reversed):
Ma = Mmax, Mm = 0
- Torsion (steady):
Tm = Tmax, Ta = 0

This loading model represents a realistic and conservative approximation of the operating conditions of a sequential gearbox and provides a consistent basis for the application of fatigue failure criteria in the following sections.

### 4.4.3 Fatigue Failure Criteria

Several fatigue failure criteria are available for the evaluation of components subjected to combined mid-range and alternating stresses. These criteria differ in their treatment of material behavior in the finite life and endurance regimes and therefore lead to different safety factor predictions. In the present work, multiple criteria are evaluated in order to provide a comprehensive comparison of the fatigue response.
Safety factors are calculated using the Goodman, Gerber, Soderberg, and ASME elliptic criteria. While results from all criteria are reported for completeness, the Goodman criterion is retained as the governing design criterion. This choice is made because of its conservative nature and its widespread use in practical mechanical design, particularly for steel components subjected to combined bending and torsional loading.

Goodman Criterion
Safety Factor Form:

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
(4 (Kf Ma)

2
+ 3 (Kf sTa)

2
)

1/2
+

1
Sut

(4 (Kf Mm)

2
+ 3 (Kf sTm)

2
)
1/2] | (1)

Diameter form:

d = [
16n
π

(
1
Se

(4 (Kf Ma)

2
+ 3 (Kf sTa)

2
)

1/2
+

1
Sut

(4 (Kf Mm)

2
+ 3 (Kf sTm)

2
)

1/2)]

1/3
| (2)

where:
- n is the fatigue safety factor
- d is the shaft diameter
- Ma

, Mm are the alternating and midrange bending moments
- Ta

, Tm are the alternating and midrange torques
- Kf

is the fatigue stress concentration factor in bending
- Kf s is the fatigue stress concentration factor in torsion
- Se

is the corrected endurance limit
- Sut is the ultimate tensile strength

Gerber Criterion
Safety Factor Form:
1
n

=

8A
πd³Se

[1 + √
1 + (

2BSe
ASut

)

2

] | (3)

Diameter Form:
d = [
8nA
πSe

(1 + √
1 + (

2BSe
ASut

)

2

)]¹/3
| (4)

where
A = √
4 (Kf Ma)

2
+ 3 (Kf sTa)

2
| (5)
B = √
4 (Kf Mm)

2
+ 3 (Kf sTm)
2 | (6)

ASME Elliptic Criterion
Safety Factor Form:

1
n

=

16
πd³

[4 (
Kf Ma
Se

)

2
+ 3 (

Kf sTa
Se

)

2
+ 4 (

Kf Mm
Sy

)

2
+ 3 (

Kf sTm
Sy

)

2
]

1/2
(7)

Diameter Form:

d = [
16n
π

(4 (
Kf Ma
Se

)

2
+ 3 (

Kf sTa
Se

)

2
+ 4 (

Kf Mm
Sy

)

2
+ 3 (

Kf sTm
Sy

)

2
)

1/2]

1/3
(8)

Soderberg Criterion
Safety Factor Form:
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
(4 (Kf Ma)

2
+ 3 (Kf sTa)

2
)

1/2
+

1
Sy

(4 (Kf Mm)

2
+ 3 (Kf sTm)

2
)
1/2] | (9)

Diameter Form:

d = [
16n
π

(
1
Se

(4 (Kf Ma)

2
+ 3 (Kf sTa)

2
)

1/2
+

1
Sy

(4 (Kf Mm)

2
+ 3 (Kf sTm)

2
)

1/2)]

1/3
(10)

Corrected Endurance Limit Se
The endurance limit of the shaft material is evaluated using the modified endurance limit expression Se = kakbkckd kekf S

′
e
where:
- ka = surface condition modification factor, Shigley’s Mechanical Engineering Design, Table 6–2
- kb = size modification factor, Shigley’s Mechanical Engineering Design, Equation 6–20
- kc = load modification factor, Shigley’s Mechanical Engineering Design, Table 6–4
- kd = temperature modification factor, Shigley’s Mechanical Engineering Design, Equation 6–27
- ke = reliability factor, Shigley’s Mechanical Engineering Design, Table 6–5
- kf = miscellaneous-effects modification factor
- S

′
e = rotary-beam test specimen endurance limit The unmodified endurance limit for steel is defined as

S

′

e = {
0.5 Sut Sut ≤ 1400 MPa

700 MPa Sut > 1400 MPa
For the material I chose
Sut = 1250 MPa
Thus
S

′
e = 0.5 Sut

Fatigue Stress Concentration Factors
Geometric discontinuities such as shoulders, grooves, and keyways introduce stress concentrations that reduce fatigue strength. The fatigue stress concentration factors in bending and torsion, denoted by Kf and Kf s, respectively, are evaluated using the relations
Kf = 1 + q(Kt − 1), Kf s = 1 + qs (Kts − 1) where Kt and Kts are the theoretical stress concentration factors, and q and qs are the notch sensitivity factors for bending and torsion.
Corresponding values for Kt and Kts are provided in Shigley’s Mechanical Engineering Design, Figure A–15–8 and Figure A–15–9.
While q and qs values are provided in Shigley’s Mechanical Engineering Design, Figure 6–20 and Figure 6–21. The obtained values for my shaft design are tabulated below.

Table 7: Theoretical stress concentration factors for the input shaft
Feature | Shaft diameter [mm] Notch radius [mm] | Kt | Kts
Shoulder bearing A | 30.0 | 1.00 | 2.30 1.90
Groove | 38.0 | 0.15 | 4.60 2.75
Keyseat (reverse gear) | 40.0 | 0.90 | 2.14 3.00
Shoulder after reverse | 40.0 | 1.50 | 1.90 1.80
Keyseat gear 1 | 50.0 | 0.90 | 2.14 3.00
Shoulder after gear 1 | 50.0 | 1.50 | 2.10 1.90
Keyseat gear 2 | 55.0 | 0.90 | 2.14 3.00
Shoulder after gear 2 | 55.0 | 1.50 | 2.18 1.45
Shoulder before gear 3 | 55.0 | 1.50 | 2.18 1.45
Keyseat gear 3 | 55.0 | 0.90 | 2.14 3.00
Shoulder after gear 3 | 50.0 | 1.50 | 2.10 1.90
Keyseat gear 4 | 50.0 | 0.90 | 2.14 3.00
Groove | 48.0 | 0.15 | 4.50 2.50
Shoulder before gear 5 | 41.7 | 1.00 | 2.30 1.90
Groove | 38.0 | 0.15 | 5.75 3.45
Shoulder bearing B | 30.0 | 1.00 | 2.30 1.90

Table 8: Theoretical stress concentration factors for the output shaft
Feature | Shaft diameter [mm] Notch radius [mm] | Kt | Kts
Shoulder bearing A | 40.0 | 1.00 | 2.40 2.00
Groove | 48.0 | 0.15 | 4.50 2.50
Shoulder after reverse | 50.0 | 1.00 | 2.30 1.65
Shoulder before gear 1 | 50.0 | 1.00 | 2.30 1.65
Shoulder after gear 1 | 45.0 | 1.00 | 2.25 1.65
Dog sleeve keyseat (gears 2–3) | 45.0 | 0.90 | 2.14 3.00
Shoulder after gear 3 | 40.0 | 1.00 | 2.25 1.55
Dog sleeve keyseat (gears 4–5) | 40.0 | 0.90 | 2.14 3.00
Groove | 38.0 | 0.15 | 4.60 2.75
Shoulder bearing B | 30.0 | 1.00 | 2.30 1.90

### 4.4.4 Input Shaft Safety Factors

The resulting fatigue failure safety factors for input shaft are tabulated below. A complete fatigue analysis was performed for all forward gears and reverse, treating each engagement as an independent load case. Among these, first gear produces the highest transmitted torque and bending moments on both the input and output shafts, resulting in the lowest fatigue safety factors. Consequently, the first gear represents the governing design case. For clarity and conciseness, detailed safety factor tables are presented only for the input and output shafts with first gear engaged. The results for the remaining gears exhibit higher safety margins and are therefore omitted from the main body of this report. However, all tables are available in the accompanying files.

Table 9: Fatigue safety factors for the input shaft – Gear 1 engaged
Feature | nGoodman | nGerber | nASME | nSoderberg
Shoulder bearing A | 2.691 | 3.259 | 2.240 | 2.562
Groove (15 mm) | 2.901 | 3.626 | 2.941 | 2.803
Keyseat reverse gear | 2.706 | 3.381 | 2.806 | 2.620
Shoulder after reverse | 2.438 | 2.895 | 2.739 | 2.394
Keyseat gear 1 | 2.344 | 2.710 | 2.621 | 2.311
Shoulder after gear 1 | 2.747 | 3.085 | 3.029 | 2.717
Keyseat gear 2 | 3.626 | 4.266 | 4.072 | 3.565
Shoulder after gear 2 | 4.258 | 4.733 | 4.664 | 4.216
Shoulder before gear 3 | 5.204 | 5.902 | 5.769 | 5.141
Keyseat gear 3 | 5.072 | 6.198 | 5.629 | 4.954
Shoulder after gear 3 | 4.746 | 5.668 | 5.330 | 4.657
Keyseat gear 4 | 4.661 | 5.791 | 5.005 | 4.529
Groove (237 mm) | 3.292 | 3.903 | 3.699 | 3.234
Shoulder before gear 5 | 5.048 | 6.310 | 5.117 | 4.877
Groove (286 mm) | 3.149 | 3.857 | 2.745 | 3.008
Shoulder bearing B | 3.342 | 3.834 | 2.346 | 3.146

### 4.4.5 Output Shaft Safety Factors

For the output shaft, the first-gear load case is governed by the dog ring location, which is positioned between the first-gear and reverse-gear regions. Therefore, the critical sections reported in Table 10 correspond to the shaft span between Gear 1 and Reverse, where the transmitted torque is effectively carried.

Table 10: Fatigue safety factors for the output shaft – Gear 1 load case.
Feature | nGoodman | nGerber | nASME | nSoderberg
Shoulder bearing A | 3.223 | 3.607 | 2.121 | 3.021
Groove (15 mm) | 3.823 | 4.580 | 3.062 | 3.631
Shoulder after reverse | 3.296 | 4.098 | 3.533 | 3.203
Shoulder before gear 1 | 2.431 | 2.942 | 2.719 | 2.380
Shoulder after gear 1 | 1.682 | 2.023 | 1.885 | 1.648
Dog sleeve keyseat (gears 2–3) | 1.758 | 2.194 | 1.726 | 1.694
Shoulder after gear 3 | 1.929 | 2.407 | 2.027 | 1.870
Dog sleeve keyseat (gears 4–5) | 1.895 | 2.219 | 1.412 | 1.791
Groove (286 mm) | 2.136 | 2.417 | 1.445 | 2.006
Shoulder bearing B | 1.601 | 1.714 | 0.947 | 1.489
a Note: While the ASME Elliptic criterion yields a value of 0.947 due to its high sensitivity to low bending moments, the more conservative Goodman criteria confirm the design is safe.

## 5 Gears Analysis

### 5.1 Gear Materials

All gears in the gearbox are manufactured from a low-carbon alloy steel specifically developed for carburizing applications. The selected material is 18CrNiMo7-6, widely used in high-performance automotive and industrial gear transmissions due to its excellent fatigue and contact strength after heat treatment.
Material selection
The material was selected to meet the following mechanical requirements:
- High contact fatigue strength (pitting resistance)
- High bending fatigue strength at the tooth root
- Tough and ductile core to withstand shock loads
- Excellent response to carburizing heat treatment
Heat treatment
The gears are carburized, quenched, and tempered, resulting in a hard wear-resistant surface layer and a tough core. Typical properties after heat treatment are:
- Surface hardness: 58−62 HRC
- Effective case depth: 0.8−1.2 mm
- Core hardness: 30−40 HRC
Mechanical strength properties
Representative strength values for carburized 18CrNiMo7-6 used in gear design are:
- Ultimate tensile strength (core): Sut ≈ 1100−1300 MPa
- Yield strength (core): Sy ≈ 850−1000 MPa
- Bending fatigue limit: Sc ≈ 550−650 MPa
- Contact fatigue limit (pitting resistance): St ≈ 1500−1700 MPa
- Young’s modulus: E ≈ 210 GPa
- Poisson’s ratio: ν ≈ 0.3
Additional useful properties
The material used is a grade 2 steel, with a quality number of 10.
Design implications
The high surface hardness and contact fatigue strength ensure safe operation under severe contact stresses, while the tough core provides resistance to shock loading and torque reversals typical of a sequential gearbox.
Even tho torque reversals were not treated in this project but the idea is to resist to this phenomena.
These strength values are fully compatible with AGMA-based bending and contact stress calculations used throughout this project.

### 5.2 Failure Safety Factors

This section presents the analytical verification of the gearbox gears with respect to strength and fatigue requirements.
Gear durability is governed by two primary and independent failure modes: tooth root bending failure and surface contact failure. Both mechanisms are critical in high-torque, high-cycle applications such as sequential gearboxes and must be evaluated separately.
Tooth root bending failure is associated with cyclic tensile stresses at the fillet region of the gear tooth and can lead to fatigue cracking and eventual tooth breakage. Surface contact failure, on the other hand, results from excessive contact stresses between mating gear teeth and manifests primarily as pitting or micropitting on the tooth flanks.
In this section, the safety factors against bending fatigue and contact fatigue are evaluated using established AGMA-based analytical formulations.

The safety factor I am after is between 1.1 and 1.3. The reason that lets me go that low on safety factor is actually because of the nature of the gearbox. The gearbox itself operates in harsh conditions, but it is not built to live as long as regular gearboxes. As mentioned before, the target service life of the gearbox is 40 000 km.
Such safety factors levels are widely common in motorsport and high-performance gearbox design practice.

### 5.2.1 Failure by bending

The bending stress at the gear tooth root is given by:

σF =

Wt Ko Kv Ks
b mn

KH KB
YJ

(11)

where:
- Wt

: transmitted tangential load [N]
- Ko

: overload factor
- Kv

: dynamic factor
- Ks

: size factor
- b : face width [mm]
- mn

: normal module [mm]
- KH : load distribution factor
- KB : rim thickness factor
- YJ

: geometry factor for bending strength (including root fillet effects) The allowable bending stress is given by:

σF ,all =

St YN
SF Yθ YZ

(12)

where:
- St

: allowable bending stress number of the material [MPa]
- YN : stress-cycle factor for bending fatigue
- Yθ

: temperature factor
- YZ : reliability factor
- SF

: bending safety factor (AGMA factor of safety) Resulting bending safety factor:
SF =

σF ,all
σF

(13)

### 5.2.2 Failure by wear (contact)

The contact stress between mating gear teeth is calculated as:

σH = ZE

√
Wt Ko Kv Ks
b dp

KH ZR
ZI

(14)

where:
- ZE : elastic coefficient [√N/mm²
]
- dp : pitch diameter of the pinion [mm]
- ZR : surface condition factor
- ZI

: geometry factor for pitting resistance

The allowable contact stress is defined as:
σH ,all =

Sc ZN ZW
SH Yθ YZ

(15)

where:
- Sc

: allowable contact stress number of the material [MPa]
- ZN : stress-cycle factor for contact fatigue
- ZW : hardness ratio factor for pitting resistance
- Yθ

: temperature factor
- YZ : reliability factor
- SH : contact safety factor (AGMA factor of safety) The resulting contact safety factor:
SH =

σH ,all
σH

(16)

### 5.2.3 Input Parameters and Assumptions

Overload Factor Ko
The power source is considered uniform (constant torque all the time), with moderate shock in terms of operating conditions, so the resulting overload factor value is Ko = 1.25.
Information regarding this parameter are provided in Shigley’s Mechanical Engineering Design, Figure 14–17. Dynamic Factor Kv
The dynamic factor Kv accounts for the increase in dynamic loads caused by gear inaccuracies, manufacturing tolerances, and vibration effects. In AGMA methodology, Kv

is related to the gear quality number Qv and the pitch line velocity.
For metric units, the dynamic factor is given by:

Kv = (

A + √200 V
A

)

B
(17)

where:
- V : pitch line velocity [m/s]
- Qv

: AGMA gear quality number The coefficients A and B are defined as:
A = 50 + 56(1 − B) | (18)
B = 0.25 (12 − Qv

)

2/3 | (19)
The pitch line velocity V is calculated as: V = π d n
60 | (20)

where:
- d : pitch diameter of the gear [m]
- n : rotational speed [rpm]
Higher values of the quality number Qv correspond to more precise gears and result in lower dynamic factors.

Size factor ks
AGMA does not provide definitive size factor values for all gear configurations. In the absence of a clearly detrimental size effect, AGMA recommends using a conservative value greater than or equal to unity. Accordingly, Ks = 1 may be assumed when size effects are negligible.
When size effects are considered, the size factor may be estimated using the AGMA-based empirical relation:

Ks =

1
kb

= 1.192 (

F√Y
P

)

0.0535
(21)

where:
- F : face width [in]
- Y : Lewis form factor, given in Shigley’s Mechanical Engineering Design, Table 14–2.
- P : diametral pitch equivalent [teeth/in]
Load Distribution Factor KH
The load distribution factor KH (also denoted Km) accounts for the nonuniform distribution of load across the gear face width caused by shaft deflection, bearing spacing, manufacturing inaccuracies, and mounting conditions. Uniform load distribution along the face width is rarely achieved in practice, particularly in compact, high-torque gearboxes.
Under AGMA assumptions (gear elements mounted between bearings and contact occurring across the full face width of the narrowest member), the load distribution factor is expressed as:
KH = Km = 1 + Cmc (Cpf Cpm + CmaCe) | (22)
- Tooth crowning factor
Cmc = {
1.0 for uncrowned teeth 0.8 for crowned teeth | (23)
- Face width factor

Cpf =

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
10dp
− 0.025, | F ≤ 1 in
F
10dp
− 0.0375 + 0.0125F , | 1 < F ≤ 17 in
F
10dp
− 0.1109 + 0.0207F − 0.000228F² | , 17 < F ≤ 40 in

(24)

where F is the face width (in) and dp is the pinion pitch diameter (in). For values of F /(10dp) < 0.05, a minimum value of 0.05 is used.
- Mounting factor

Cpm = {
1.0 for straddle-mounted pinion with S1/S < 0.175 1.1 for straddle-mounted pinion with S1/S ≥ 0.175

(25)

where S is the total distance between 2 bearings and S1

is the distance from gear face to the center.
- Manufacturing and alignment factor
Cma = A + BF + CF ²
(26)

where the coefficients A, B, and C depend on the gear manufacturing quality and are selected from AGMA reference tables, provided in Shigley’s Mechanical Engineering Design, Table 14–9.
- Assembly factor
Ce = {
0.8 for gears adjusted at assembly or lapped 1.0 for all other conditions

(27)

The factor KH is applied in both bending and contact stress equations and plays a critical role in accounting for load misalignment effects in real gearbox assemblies.
Rim Thickness Factor KB
Assumed I am dealing with constant thickness gears, the resulting rim thickness factor KB = 1.
Geometry Factor for Bending Strength YJ
This factor depends on the gear’s pressure angle, the module and the number of teeth on both the pinion and the mating gear.
These values can be obtained with the help of Figure 14–6, in Shigley’s Mechanical Engineering Design.

### 5.3 Safety Factors Results

Table 11: Summary of Gears Safety Factors
Gear | Module Number of Face width Bending safety factor Contact safety factor
| | teeth | [mm] | | (failure by wear)
Gear 1 input | 3.0 | 25 | 40 | 1.2832 | 1.3155
Gear 1 output | 3.0 | 63 | 40 | 1.3008 | 1.3419
Gear 2 input | 3.0 | 31 | 30 | 1.2621 | 1.3273
Gear 2 output | 3.0 | 57 | 30 | 1.2710 | 1.3434
Gear 3 input | 3.0 | 37 | 25 | 1.2966 | 1.3658
Gear 3 output | 3.0 | 51 | 25 | 1.3015 | 1.3746
Gear 4 input | 3.0 | 41 | 25 | 1.4347 | 1.4366
Gear 4 output | 3.0 | 47 | 25 | 1.4370 | 1.4405
Gear 5 input | 3.0 | 49 | 20 | 1.3997 | 1.3961
Gear 5 output | 3.0 | 39 | 20 | 1.3960 | 1.3897
Reverse gear in | 2.5 | 31 | 40 | 1.2627 | 1.4319
Reverse gear out | 2.5 | 68 | 40 | 1.2767 | 1.4558

## 6 Keys

### 6.1 General Description

Torque transmission between the shafts and the mounted gears in the sequential gearbox is ensured using nonstandard parallel keys. Unlike conventional catalog keys, these keys were specifically dimensioned and verified by calculation to match the transmitted torque levels and packaging constraints of the gearbox.
All keys used in this design are manufactured from AISI 4340 steel in the normalized condition, with the following mechanical properties:
- Ultimate tensile strength: Sut = 1110 MPa
- Yield strength: Sy = 710 MPa

Failure at keys can be 2 types: failure by crushing and failure by shear. Both safety factors should meet the requirements to consider the key as acceptable. More details in the upcoming paragraphs.

### 6.2 Torque Transmission

The torque transmitted through the shaft produces a tangential force acting on the key, given by:

| | | Ft =

2T
d

(28)

where:
- T is the transmitted torque,
- d is the shaft diameter.
This tangential force is responsible for both shear stress within the key and bearing stress at the key–shaft and key–hub interfaces.

### 6.3 Shear Failure of the Key

The average shear stress in the key is expressed as:

τ =

Ft
b l | (29)

where:
- b is the key width,
- l is the effective key length.
The allowable shear stress for ductile steel is taken as:
τallow = 0.30 σy | (30)
The shear safety factor is therefore:

nshear =

τallow
τ
| (31)

### 6.4 Crushing (Bearing) Failure of the Key

The bearing stress acting on the key is given by:

σc =

Ft
ℎ l | (32)

where ℎ is the effective bearing height of the key. Both the key–shaft and key–hub interfaces are considered in the evaluation.
The allowable bearing stress is defined as:
σc,allow = 0.6 Sy | (33)
The corresponding crushing safety factor is:

ncrushing =

σc,allow
σc
| (34)

### 6.5 Conclusion

All keys in the gearbox were verified against shear and crushing failure using the above criteria. The use of high-strength AISI 4340 normalized steel ensures sufficient load-carrying capacity, desired safety factor levels and packaging requirements of the sequential gearbox design.
Results are tabulated below (an extended table can be found in the additional documents).

Table 12: Safety Factors of Keyed Connections
Location | nshear | ncrushing,shaft | ncrushing,hub | Governing Mode
Input shaft – reverse gear | 2.84 | 2.92 | 3.15 | Shear
Input shaft – gear 1 | 3.55 | 3.65 | 3.94 | Shear
Input shaft – gear 2 | 2.60 | 2.68 | 2.89 | Shear
Input shaft – gear 3 | 2.60 | 2.68 | 2.89 | Shear
Input shaft – gear 4 | 2.37 | 2.43 | 2.62 | Shear
Input shaft – flange | 1.78 | 1.82 | 1.80 | Shear
Dog ring sleeve (2–3) | 1.95 | 1.67 | 1.72 | Crushing
Dog ring sleeve (4–5) | 2.58 | 2.21 | 2.28 | Crushing

The target safety factor is around n = 1.3 − 1.5 as the design target for all keyed connections. All evaluated key locations satisfy this criterion with comfortable margins.
Increasing the safety factor of keyed joints does not introduce any penalty in terms of mass, packaging, or dynamic behavior. On the contrary, keys are simple, low-cost, and easily replaceable components, making conservative design choices acceptable and even desirable.
In certain locations, the yield strength used in the crushing verification may correspond to either the key material, the shaft material, or the hub material. This choice can slightly affect the numerical value of the crushing safety factor. However, regardless of this assumption, all results remain well within the acceptable design range, and no keyed joint approaches a critical failure condition.

## 7 Splines

### 7.1 General Description

Spline connections are used in the sequential gearbox to transmit torque while allowing axial sliding between components, notably for the dog ring sleeves. Unlike keys, splines distribute the transmitted torque over multiple teeth, leading to improved load sharing and reduced stress concentration.
All spline connections in this gearbox were selected and dimensioned in accordance with the DIN 5480 standard, which defines the geometry, tolerances, and load-carrying capacity of involute splines. The spline sizes were chosen based on the transmitted torque, shaft diameter, and packaging constraints, ensuring compatibility with standardized manufacturing practices and reliable load distribution.

### 7.2 Load Transmission Mechanism

In a splined joint, torque is transmitted through compressive contact(bearing) between the spline teeth of the shaft and the mating hub. The load is distributed over several teeth simultaneously, depending on manufacturing tolerances, elastic deformation, and contact conditions.
The tangential force corresponding to the transmitted torque is given by:

Ft =

2T
dm

(35)

where:
- T is the transmitted torque,
- dm is the mean spline diameter.
This force is shared among the engaged spline teeth.

### 7.3 Failure Mode Consideration

For spline connections, only crushing (bearing) failure is considered in the design verification. Shear failure is not evaluated because:
- Torque transmission does not rely on a single shear plane, as in keyed joints
- The spline teeth are integral to the shaft and hub, eliminating a discrete shear element
- Load transfer occurs primarily through surface contact pressure rather than material shearing. Consequently, the governing failure mechanism for splines is crushing(bearing) stress at the tooth contact surfaces.

### 7.4 Crushing (Bearing) Stress in Splines

The average bearing stress in the splines is expressed as:

σc =

Ft
N Ac

(36)

where:

- N is the number of load-carrying spline teeth,
- Ac

is the effective contact area per tooth.
The allowable bearing stress is taken as a fraction of the yield strength of the weaker material between the shaft and the hub:

σc,allow = 0.6 Sy

(37)
The crushing safety factor is therefore:

ncrushing =

σc,allow
σc

(38)

### 7.5 Conclusion

All spline connections were verified against crushing failure and satisfy the design requirement with safety factors greater than the target value. Results are tabulated below.

Table 13: Crushing Safety Factors of Spline Connections
Location | ncrushing
Input shaft – gear 5 | 6.64
Output shaft – gear 1 / reverse | 1.60
Dog ring sleeve (gears 2–3) | 3.84
Dog ring sleeve (gears 4–5) | 3.84
Output shaft flange | 3.22

## 8 Bearings

### 8.1 Bearing Life Theory

Bearing life is evaluated using the basic rating life formulation as defined in Shigley’s Mechanical Engineering Design. The basic rating life, expressed in millions of revolutions, is given by:

L10 = (

C
P

)

p
(39)

where:
- L10 is the basic rating life (in 10⁶
revolutions)
- C is the basic dynamic load rating of the bearing
- P is the equivalent dynamic bearing load
- p is the life exponent (p = 3 for ball bearings, p = 10
3

for roller bearings)

### 8.2 Equivalent Dynamic Load

For combined radial and axial loading, the equivalent dynamic bearing load is defined as:

P = X V Fr + Y Fa

(40)
where:
- Fr

is the radial bearing load
- Fa

is the axial bearing load
- X and Y are load factors dependent on the bearing type and load ratio (with X = 1 and Y = 0 for spur gears)

In the expression of the equivalent dynamic bearing load, a rotation factor V is introduced to account for the rotation of the inner or outer ring. For most rolling-element bearings operating under normal conditions, this factor is taken as V = 1. The value V = 1.2 is occasionally used to account for unfavorable outer-ring rotation, as it reflects a reduction in fatigue life under such conditions.
In the present gearbox design, main bearings operate with a rotating inner ring and a stationary outer ring. Therefore, the rotation factor is taken as V = 1, in accordance with standard practice and the recommendations provided in Shigley’s Mechanical Engineering Design.

### 8.3 Bearing Life in Operating Hours

The bearing life expressed in operating hours is obtained from:

L10ℎ =

10⁶L10
60n

(41)

where:
- L10ℎ is the bearing life in hours
- n is the rotational speed in revolutions per minute (I chose 4000 rpm as the average gearbox’s shaft rotation speed)

### 8.4 Variable Load and Speed Conditions

When bearings operate under variable loads and speeds, an equivalent bearing load is defined using a timeweighted formulation:

Peq = (
∑i
ni P

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
(42)

where:
- Pi

is the equivalent dynamic load during operating condition i
- t
i

is the time spent in condition i
- p is the bearing life exponent
This equivalent load is then used in the basic rating life equation.

### 8.5 Design Criterion

For each bearing location, an equivalent dynamic load Peq is first computed from the duty cycle. The bearing is then selected from manufacturer catalogs such that its basic dynamic load rating C10 satisfies:

C10 ≥ Peq | (43)
This criterion ensures that the chosen bearing has sufficient dynamic load capacity for the intended operating conditions. A bearing with a higher C10 than Peq provides additional life margin.

### 8.6 Results and Bearing Selection

After applying the duty-cycle-based formulation, the equivalent dynamic bearing loads were found to be:
- Input shaft: Peq = 43.8 kN
- Output shaft: Peq = 38.2 kN
After consulting manufacturer catalogs, the following cylindrical roller bearings were selected for use in the gearbox:
- NUP 2206 ECP (bore diameter 30 mm, width 20 mm, C10 = 55 kN)
- NUP 207 ECP (bore diameter 35 mm, width 17 mm, C10 = 56 kN)

- NUP 208 ECP (bore diameter 40 mm, width 18 mm, C10 = 62 kN)
All selected bearings have basic dynamic load ratings exceeding the calculated equivalent loads, thereby satisfying the adopted design criterion (C10 > Peq). The use of cylindrical roller bearings is well suited to the high radial loads encountered in the gearbox and provides adequate margin with respect to bearing life.

### 8.7 Other Bearings

Other bearings were also used in this gearbox design. These bearings are located between the output shaft and output gears bore and they are used to allow free rotation of output gears,
All those bearings were chosen from catalogs without additional calculations. I mainly chose NTN needle bearings, and below, a table that contain each gear with its corresponding bearing.

Table 14: Needle Bearings Used for Gear Support Gear location Needle bearing reference
Output gear 1 | NA6190R
Output gear 2 | NA5909
Output gear 3 | NK50_25RCT + IR45x50x25
Output gear 4 | NA4908R
Output gear 5 | NK45_20R + IR40x45x20
Reverse gear | NA6190R

## 9 Engagement Mechanism

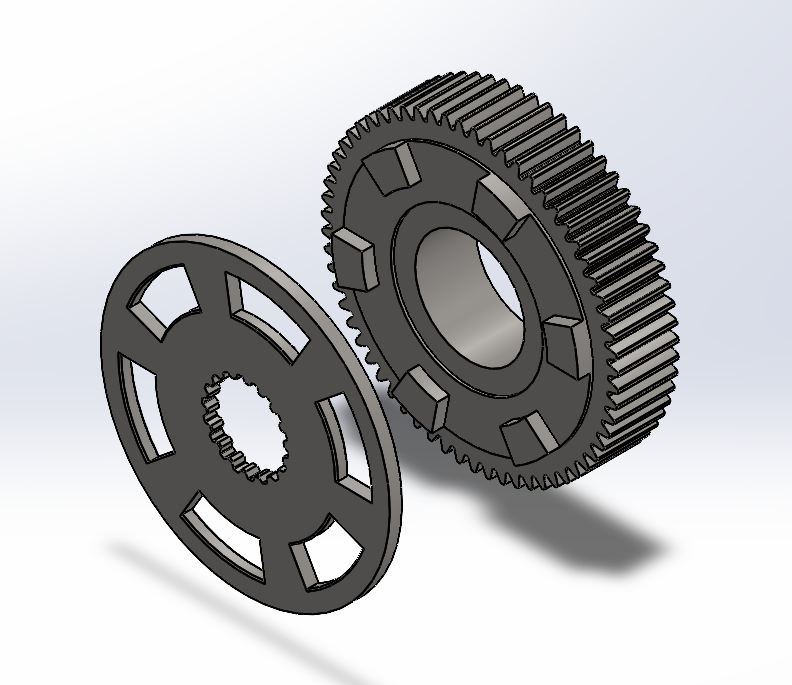
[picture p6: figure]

Figure 2: Dog ring engagement with gear dog teeth

### 9.1 Principle of Operation

Gear engagement in the sequential gearbox is achieved using a dog ring mechanism. Each selectable gear is permanently in mesh with its mating gear, while torque transmission is controlled by axial engagement of a sliding dog ring.
The dog ring is splined to the shaft, allowing it to slide axially while remaining rotationally constrained. When actuated, the dog ring moves along the shaft and engages with the dog teeth machined on the face of the gear. Once engaged, torque is transmitted directly through the contacting dog teeth, locking the gear to the shaft.

### 9.2 Engagement and Disengagement

During a gear change, the dog ring disengages from the currently engaged gear and slides axially toward the target gear. Engagement occurs when the dog teeth of the ring align and enter the corresponding recesses on the gear face. Successful engagement results in a rigid mechanical connection between the gear and the shaft. Disengagement is achieved by reversing the axial motion of the dog ring, freeing the gear while it remains in constant mesh with its counterpart.

### 9.3 Design Characteristics

Unlike synchronizers, the dog ring mechanism does not rely on friction to match rotational speeds. Engagement therefore occurs under conditions of reduced load or momentary torque interruption, which is consistent with the operating principle of a sequential gearbox. The simplicity and robustness of the dog ring mechanism make it well suited for performance-oriented applications, where rapid gear changes and positive engagement are required.
Below is a simple sketch of all dog rings designed and used in the gearbox.

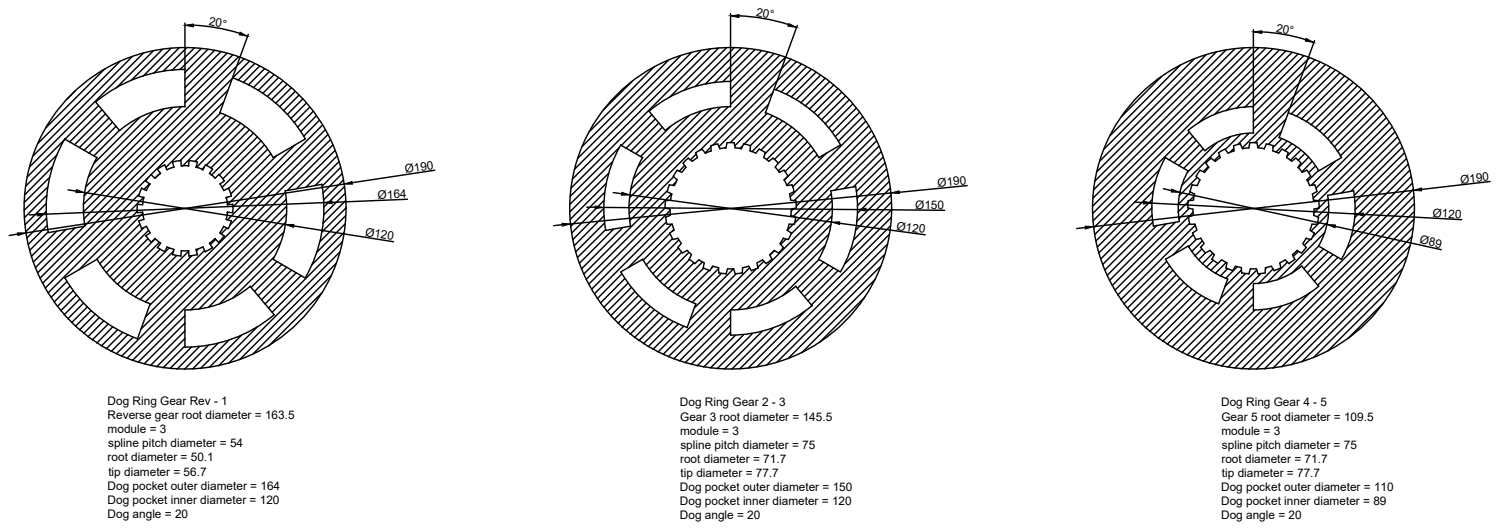
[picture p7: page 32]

Dog Ring Gear Rev - 1
Reverse gear root diameter = 163.5 module = 3

Dog Ring Gear 2 - 3 Gear 3 root diameter = 145.5 module = 3

Dog Ring Gear 4 - 5 Gear 5 root diameter = 109.5 module = 3

spline pitch diameter = 54
root diameter = 50.1
tip diameter = 56.7
Dog pocket outer diameter = 164
Dog pocket inner diameter = 120
Dog angle = 20

spline pitch diameter = 75
root diameter = 71.7
tip diameter = 77.7
Dog pocket outer diameter = 150

Dog pocket outer diameter = 110
Dog pocket inner diameter = 89

### 9.4 Dog Clutch Failure Checks

Dog clutches are checked against crushing failure of the dog faces and shear failure of the dogs. Torque transmission is assumed to occur through face contact between engaged dogs.

### 9.4.1 Tangential Force at Dog Radius

The transmitted torque T produces a tangential force at the mean dog radius:

Ft =

T
rm

(44)

where rm is the mean radius of the dog engagement.

### 9.4.2 Crushing Failure of Dog Faces

The average bearing (crushing) stress on the engaged dog faces is:

σc =

Ft
Ne Ad

(45)

where:
- Ad

is the contact area of one dog
- Ne

is the effective number of dogs carrying load (value is usually somewhere between 0.25-0.3, for this gearbox design I chose 0.3)
The crushing safety factor is defined as:

ncrushing =

σc,allow
σc

(46)

with:
σc,allow = 0.6 Sy

(47)

### 9.4.3 Shear Failure of Dogs

Each dog is also checked in shear at its root section. The average shear stress in one dog is:

τ =

Ft
Ne As

(48)

where As

is the shear area of one dog (root cross-section). The shear safety factor is given by:

nshear =

τallow
τ

(49)

with:
τallow = 0.3 Sy

(50)

### 9.4.4 Results

Safety factors obtained are tabulated below.

Table 15: Dog Ring Geometry and Safety Factors
Dog ring | Number of | Axial | Radial | Arc | Failure by shear Failure by crushing
dogs/teeth length width | length
Reverse – gear 1 | 6 | 8 | 20 | 7.9744 | 4.2835 | 8.5946
Gear 2 – 3 | 6 | 8 | 10 | 8.4569 | 2.9354 | 5.5535
Gear 4 – 5 | 6 | 8 | 10 | 11.5167 | 4.7984 | 6.6663

## 10 Design Summary

The sequential gearbox was designed following a structured and coherent approach. Gear geometry was defined to satisfy torque and speed requirements, while shafts were dimensioned and verified against combined loading conditions. Bearing selection was performed using duty-cycle-based equivalent loads, and all selected bearings satisfy the adopted dynamic load rating criterion.
Torque transmission elements, including keys, splines, and dog clutches, were verified against their governing failure modes with safety factors exceeding the design targets. The engagement mechanism ensures positive gear selection while maintaining mechanical simplicity and robustness.

## 11 Design Assumptions and Limitations

The present design is based on analytical calculations and standardized design methods. Dynamic effects during gear engagement, manufacturing tolerances, and thermal effects were not explicitly modeled. Load sharing assumptions were made for splines and dog clutches, and fatigue effects were not considered for engagement components.
Despite these simplifications, the design remains representative of a realistic sequential gearbox and provides sufficient safety margins for the intended operating conditions.

## 12 Supporting Material

For clarity and conciseness, the main body of this report presents only the most critical design cases. Additional tables containing detailed calculations, secondary loading cases, and extended design data are provided alongside this report.
Furthermore, complete technical drawings of the components, as well as assembly models and views of the gearbox, are included as supporting material. These documents ensure full traceability of the design and provide the necessary information for further analysis.

## 13 Conclusion

This project was carried out with the objective of developing a sequential gearbox design that could realistically be taken beyond the conceptual stage and into manufacturing. All verification and validation performed within this report are based on analytical and theoretical methods; no experimental testing or physical validation has been conducted at this stage. As such, the present work should be regarded as a solid design foundation rather than a finalized, validated product.

Beyond the technical results, this project served as an in-depth learning experience in mechanical design. Particular emphasis was placed on understanding design assumptions: when they are required, when they are valid, and how they affect the interpretation of results. The project required continuous judgment in balancing analytical rigor with practical simplifications, reflecting the reality of real-world engineering design.

A wide range of drivetrain mechanisms had to be thoroughly understood in order to be correctly implemented, including gears, shafts, bearings, splines, keys, dog clutches, and engagement mechanisms. Unlike conventional reducers or speed-increasing gearboxes with fixed operating conditions, this sequential gearbox combines multiple operating cases within a single architecture. Each gear engagement represents a distinct load case, requiring careful evaluation of the most critical conditions while ensuring overall design coherence.

Countless hours were invested in iterating the design, studying standards, verifying critical cases, and refining the gearbox architecture. This work represents a deliberate effort to bridge theoretical knowledge with practical mechanical design, and it provides a strong basis for further refinement, manufacturing, or experimental validation.

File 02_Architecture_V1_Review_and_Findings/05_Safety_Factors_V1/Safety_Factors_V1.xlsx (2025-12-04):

 | troque transmission way | torque [Nm] | dimensions [mm] | yield strength [Mpa] | safety factors | Notes
dog sleeve between reverse and gear 1 | key | 1457.1 | diameter = 50 key length = l = 20 key width = b = 12 key height = h = 14 deepness in shaft = 0.4*h = 5.6 deepness in hub = 0.6*h =8.4 | Sy_key = 710; AISI 4340, normalized Sy_shaft = 1140; AISI 4140 Q&T Sy_hub = 820; 18CrNiMo7-6 | failure by shear = 0.8771 failure by crushing ( shaft ) = 1.3145 failure by crushing ( hub ) = 1.4183 | safety factors too low to be accepted need more contact length between the ring and the key key height must be reduced switching to a spline is the best option
dog ring between reverse and gear 1 | spline | 1457.1 | pressure angle = 30 degrees module: m = 3 pitch diameter = 90 addendum = 0.45*m = 1.35 dedendum = 0.55*m = 1.65 | Sy_sleeve = 820; 18CrNiMo7-6 | failure by shear = 14.3589 failure by crushing = 14.3589 | very high safety factors because of the usage of spline instead of keys
dog ring between gear 2 and gear 3 | key | 1218.7 | diameter = 70 key length = l = 10 key width = b = 12 key height = h = 14 deepness in shaft = 0.4*h = 5.6 deepness in hub = 0.6*h =8.4 | Sy_key = 710; AISI 4340, normalized Sy_shaft = 1140; AISI 4140 Q&T Sy_hub = 820; 18CrNiMo7-6 | failure by shear = 0.7341 failure by crushing ( shaft ) = 1.3751 failure by crushing ( hub ) = 0.9891 | safety factors too low to be accepted
dog ring between gear 4 and gear 5 | key | 763.65 | diameter = 50 key length = l = 10 key width = b = 12 key height = h = 14 deepness in shaft = 0.4*h = 5.6 deepness in hub = 0.6*h =8.4 | Sy_key = 710; AISI 4340, normalized Sy_shaft = 1140; AISI 4140 Q&T Sy_hub = 820; 18CrNiMo7-6 | failure by shear = 1.6735 failure by crushing ( shaft ) = 1.7914 failure by crushing ( hub ) = 1.9328 | safety factors are acceptable key height and overall dimensions remains a problem ( key too large)
coupling at input shaft | spline | 450 | pressure angle = 30 degrees module: m = 1.5 pitch diameter = 37.5 addendum = 0.45*m = 0.675 dedendum = 0.55*m = 0.825 | Sy_shaft = 1140 Sy_coupling = 1140; AISI 4140 Q&T | failure by shear = 2.5180 failure by crushing = 3.2062 | safety factos are acceptable this coupling is transmitting torque from engine to input shaft
coupling at output shaft | spline | 1457.1 | pressure angle = 30 degrees module: m = 1.5 pitch diameter = 37.5 addendum = 0.45*m = 0.675 dedendum = 0.55*m = 0.825 | Sy_shaft = 1140 Sy_coupling = 1140; AISI 4140 Q&T | failure by shear = 1.9441 failure by crushing = 2.4755 | safety factors are acceptable this coupling is transmitting torque to differential out of the gearbox designed at the highest troque possible, when gear 1 is engaged
dogs (dog ring teeth) - reverse and gear 1 | dog - dog pockets | 1457.1 | diameter_gear = 238; diameter_dogs = 160; dog_engagement_height = 7; axial dog_thickness = 20; radial dog_length = 15; tangential | Sy_ring = 800; 18CrNiMo7-6 | failure by shear = 6.6416 failure by crushing = 7.1160 | safety factors are calculated in the case of highest torque the surface is treated as a rectangle and not a radial surface to simplify calculations this simplification is conservative, doesn't affect the results by much
dogs (dog ring teeth) - gear 2 and gear 3 | dog - dog pockets | 1218.7 | diameter_gear = 213.5; diameter_dogs = 140; dog_engagement_height = 7; axial dog_thickness = 20; radial dog_length = 15; tangential | Sy_ring = 800; 18CrNiMo7-6 | failure by shear = 6.9477 failure by crushing = 7.4440 | safety factors are calculated in the case of highest torque the surface is treated as a rectangle and not a radial surface to simplify calculations this simplification is conservative, doesn't affect the results by much
dogs (dog ring teeth) - gear 4 and gear 5 | dog - dog pockets | 763.65 | diameter_gear = 168; diameter_dogs = 117.5; dog_engagement_height = 7; axial dog_thickness = 15; radial dog_length = 15; tangential | Sy_ring = 800; 18CrNiMo7-6 | failure by shear = 6.9794 failure by crushing = 7.4779 | safety factors are calculated in the case of highest torque the surface is treated as a rectangle and not a radial surface to simplify calculations this simplification is conservative, doesn't affect the results by much

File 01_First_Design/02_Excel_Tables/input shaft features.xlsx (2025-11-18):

Input Shaft Reverse Gear
feature | location [mm] | Mxy [Nm] | Mxz [Nm] | Mmax [Nm] | Tmax [Nm] | Ma [Nm] | Mm [Nm] | Ta [Nm] | Tm [Nm] | shaft diameter [mm] | notch radius [mm] | kt | kts | SF_Goodman | SF_Gerber | SF_ASMEelliptic | SF_Soderberg
shoulder bearing A | 11.45 | 130.0033 | -47.3174 | 138.3466456 | 450 | 138.3466456 | 0 | 0 | 450 | 40 | 1.00 | 2.43 | 2.00 | 4.4804 | 5.5963 | 4.4411 | 4.3208
groove | 19.73 | 224.0144 | -81.5346 | 238.3911542 | 450 | 238.3911542 | 0 | 0 | 450 | 47 | 0.15 | 5.40 | 3.15 | 2.879 | 3.4693 | 3.2256 | 2.8204
keyseat reverse gear | 38.23 | 434.0634 | -157.9862 | 461.9206367 | 450 | 461.9206367 | 0 | 0 | 450 | 50 | 0.90 | 2.25 | 3.15 | 3.531 | 4.302 | 3.9298 | 3.4516
shoulder after reverse | 55.65 | 407.8794 | -148.4558 | 434.0561363 | 450 | 434.0561363 | 0 | 0 | 450 | 50 | 1.50 | 2.15 | 1.50 | 4.4005 | 5.0737 | 4.9152 | 4.3388
groove | 78.58 | 373.4133 | -135.9108 | 397.3779538 | 450 | 397.3779538 | 0 | 0 | 450 | 52 | 0.18 | 5.10 | 3.00 | 2.6583 | 3.052 | 2.9641 | 2.6224
keyseat gear 1 | 97.08 | 345.606 | -125.7894 | 367.7859165 | 450 | 367.7859165 | 0 | 0 | 450 | 55 | 0.90 | 2.35 | 3.20 | 5.298 | 6.5376 | 5.7974 | 5.1621
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

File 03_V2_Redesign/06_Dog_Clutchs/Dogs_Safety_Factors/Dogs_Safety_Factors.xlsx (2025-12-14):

Dog ring | number of dogs/teeth | axial length | radial width | arc length | failure by shear | failure by crushing
reverse - gear 1 | 6 | 8 | 20 | 7.9744 | 4.2835 | 8.5946
gear 2 - 3 | 6 | 8 | 10 | 8.4569 | 2.9354 | 5.5535
gear 4 - 5 | 6 | 8 | 10 | 11.5167 | 4.7984 | 6.6663

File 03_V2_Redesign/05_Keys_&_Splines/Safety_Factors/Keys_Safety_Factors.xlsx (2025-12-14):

location | shaft diameter [mm] | key length [mm] | key width [mm] | key height [mm] | height in shaft | height in hub | hub material | yield strength Sy [MPa] | failure by shear | failure by crushing shaft | failure by crushing hub
input shaft reverse gear keyseat | 40 | 30 | 10 | 8 | 0.4*(key height) | 0.6*(key height) | 18CrNiMo7-6 | 820 | 2.84 | 2.9184 | 3.1488
input shaft gear 1 keyseat | 50 | 30 | 10 | 8 | 0.4*(key height) | 0.6*(key height) | 18CrNiMo7-6 | 820 | 3.55 | 3.648 | 3.936
input shaft gear 2 keyseat | 55 | 20 | 10 | 8 | 0.4*(key height) | 0.6*(key height) | 18CrNiMo7-6 | 820 | 2.6033 | 2.6752 | 2.8864
input shaft gear 3 keyseat | 55 | 20 | 10 | 8 | 0.4*(key height) | 0.6*(key height) | 18CrNiMo7-6 | 820 | 2.6033 | 2.6752 | 2.8864
input shaft gear 4 keyseat | 50 | 20 | 10 | 8 | 0.4*(key height) | 0.6*(key height) | 18CrNiMo7-6 | 820 | 2.3667 | 2.432 | 2.624
input shaft input flange keyway | 25 | 30 | 10 | 8 | 0.4*(key height) | 0.6*(key height) | 42CrMo | 750 | 1.775 | 1.824 | 1.8
dog ring sleeve gear 2 - 3 | 45 | 28 | 12 | 8 | 0.4*(key height) | 0.6*(key height) | 18CrNiMo7-6 | 785 | 1.9462 | 1.6666 | 1.7214
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

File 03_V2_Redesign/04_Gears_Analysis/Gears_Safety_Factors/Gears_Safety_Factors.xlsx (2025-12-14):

gear | module | number of teeth | face width [mm] | bending safety factor | contact safety factor (failure by wear)
gear 1 input | 3 | 25 | 40 | 1.2832 | 1.3155
gear 1 output | 3 | 63 | 40 | 1.3008 | 1.3419
gear 2 input | 3 | 31 | 30 | 1.2621 | 1.3273
gear 2 output | 3 | 57 | 30 | 1.271 | 1.3434
gear 3 input | 3 | 37 | 25 | 1.2966 | 1.3658
gear 3 output | 3 | 51 | 25 | 1.3015 | 1.3746
gear 4 input | 3 | 41 | 25 | 1.4347 | 1.4366
gear 4 output | 3 | 47 | 25 | 1.437 | 1.4405
gear 5 input | 3 | 49 | 20 | 1.3997 | 1.3961
gear 5 output | 3 | 39 | 20 | 1.396 | 1.3897
reverse gear input | 2.5 | 31 | 40 | 1.2627 | 1.4319
reverse gear output | 2.5 | 68 | 40 | 1.2767 | 1.4558

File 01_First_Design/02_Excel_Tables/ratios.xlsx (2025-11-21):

diameter in inch
speed | i | zin | zout | din | dout | center to center distance | speed | module | i | zin | zin integer | zout | zout integer | din | dout | CD
1 | 3.6 | 23 | 84 | 2.875 | 10.5 | 6.6875 | 1 | 3.5 | 3.238 | 21 | 21 | 67.998 | 68 | 73.5 | 238 | 155.75
2 | 2.55 | 31 | 79 | 3.875 | 9.875 | 6.875 | 2 |  | 2.7083 | 24 | 24 | 64.9992 | 65 | 84 | 227.5 | 155.75
3 | 1.79 | 37 | 66 | 4.625 | 8.25 | 6.4375 | 3 |  | 2.1786 | 28 | 28 | 61.0008 | 61 | 98 | 213.5 | 155.75
4 | 1.25 | 45 | 56 | 5.625 | 7 | 6.3125 | 4 |  | 1.697 | 33 | 33 | 56.001 | 56 | 115.5 | 196 | 155.75
5 | 0.87 | 51 | 44 | 6.375 | 5.5 | 5.9375 | 5 |  | 1.1707 | 41 | 41 | 47.9987 | 48 | 143.5 | 168 | 155.75
 |  |  |  |  |  |  | reverse |  | 3.05 | 20 | 20 | 61 | 61 | 70 | 213.5 | 155.75
Second assumption (taking into consideration the center to center distance) |  |  |  |  |  |  | idler |  |  | 19 | 19 |  |  | 66.5
speed | i | zin | zout | din | dout | center to center distance
1 | 3.6 | 23 | 84 | 2.875 | 10.5 | 6.6875
2 | 2.55 | 30 | 77 | 3.75 | 9.625 | 6.6875
3 | 1.74 | 39 | 68 | 4.875 | 8.5 | 6.6875
4 | 1.32 | 46 | 61 | 5.75 | 7.625 | 6.6875
5 | 0.87-0.88 | 57 | 50 | 7.125 | 6.25 | 6.6875

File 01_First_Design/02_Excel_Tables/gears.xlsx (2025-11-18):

gear | in/out | bending safety factor | pitting safety factor
reverse | input | 1.2677 | 1.3449
 | output | 1.2837 | 1.3748
1 | input | 1.1731 | 1.2335
 | output | 1.1879 | 1.2618
2 | input | 1.3884 | 1.3517
 | output | 1.4044 | 1.3787
3 | input | 1.6628 | 1.5019
 | output | 1.6779 | 1.5254
4 | input | 1.9943 | 1.6866
 | output | 2.0065 | 1.7044
5 | input | 2.5485 | 1.9400
 | output | 2.5533 | 1.9461

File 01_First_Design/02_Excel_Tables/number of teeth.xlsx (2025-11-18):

speed | module | i | zin | zin integer | zout | zout integer | din | dout | CD
1 | 3.5 | 3.238 | 21 | 21 | 67.998 | 68 | 73.5 | 238 | 155.75
2 |  | 2.7083 | 24 | 24 | 64.9992 | 65 | 84 | 227.5 | 155.75
3 |  | 2.1786 | 28 | 28 | 61.0008 | 61 | 98 | 213.5 | 155.75
4 |  | 1.697 | 33 | 33 | 56.001 | 56 | 115.5 | 196 | 155.75
5 |  | 1.1707 | 41 | 41 | 47.9987 | 48 | 143.5 | 168 | 155.75
reverse |  | 3.05 | 20 | 20 | 61 | 61 | 70 | 213.5 | 155.75
idler |  |  | 19 | 19 |  |  | 66.5

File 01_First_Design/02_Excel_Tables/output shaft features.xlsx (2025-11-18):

output shaft reverse gear
feature | location [mm] | Mxy [Nm] | Mxz [Nm] | Mmax [Nm] | Tmax [Nm] | Ma [Nm] | Mm [Nm] | Ta [Nm] | Tm [Nm] | shaft diameter [mm] | notch radius [mm] | kt | kts | SF_Goodman | SF_Gerber | SF_ASMEelliptic | SF_Soderberg
shoulder bearing A | 11.45 | 130.0033 | -47.3173 | 138.3466114 | 1373 | 69.17330571 | 69.17330571 | 686.5 | 686.5 | 40 | 1.2 | 2.30 | 1.88 | 1.7196 | 2.0708 | 1.9271 | 1.6848
groove | 19.73 | 224.0144 | -81.5346 | 238.3911542 | 1373 | 119.1955771 | 119.1955771 | 686.5 | 686.5 | 47 | 0.15 | 5.40 | 3.15 | 1.7634 | 2.1204 | 1.9773 | 1.7282
dog keyseat R-1 | 67.65 | 389.8408 | -141.8904 | 414.859898 | 1373 | 207.429949 | 207.429949 | 686.5 | 686.5 | 50 | 0.9 | 2.25 | 3.15 | 1.9811 | 2.3808 | 2.2218 | 1.9417
shoulder 1-2 | 116.5 | 316.4121 | -115.1646 | 336.7187285 | 1373 | 168.3593642 | 168.3593642 | 686.5 | 686.5 | 50 | 1.5 | 2.3 | 1.8 | 3.2589 | 3.9164 | 3.6548 | 3.1942
shoulder 2-3 | 151.5 | 263.802 | -96.0161 | 280.732233 | 1373 | 140.3661165 | 140.3661165 | 686.5 | 686.5 | 60 | 2 | 2.28 | 1.75 | 5.7307 | 6.8702 | 6.4312 | 5.6191
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

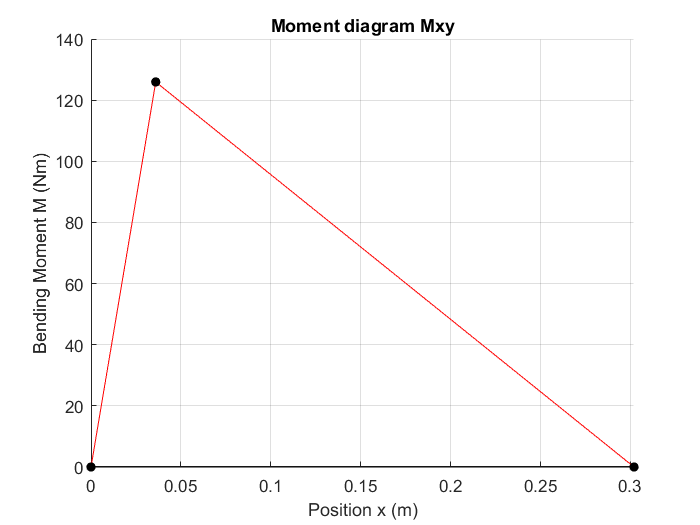
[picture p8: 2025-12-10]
03_V2_Redesign/02_Input_Shaft_Analysis/Moment_Diagrams/Input_Shaft_Reverse_Gear/Mxy.png

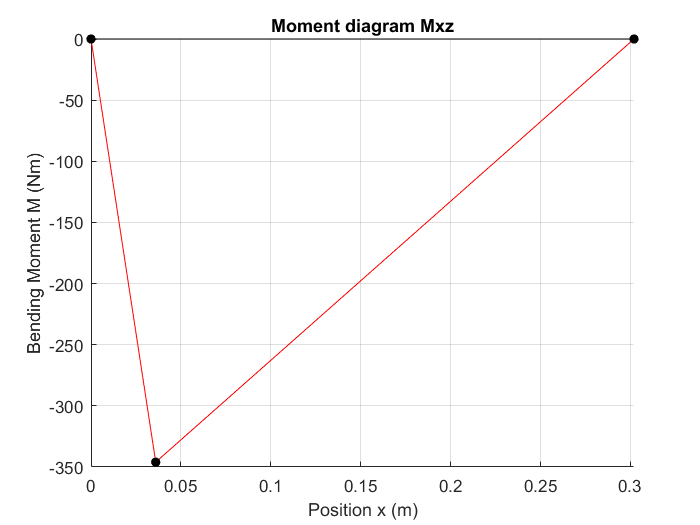
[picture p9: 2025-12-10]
03_V2_Redesign/02_Input_Shaft_Analysis/Moment_Diagrams/Input_Shaft_Reverse_Gear/Mxz.png

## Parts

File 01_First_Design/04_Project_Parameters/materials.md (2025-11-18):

# Materials

## Shaft Material

- **Steel:** AISI 4140  
- **Condition:** Quenched and tempered at 425 °C  
- **Ultimate tensile strength, S_ut:** 1250 MPa  
- **Yield strength, S_y:** 1140 MPa  

This material is used for the gearbox shafts in this first complete
acceptable design. These mechanical properties are the reference values
used in the shaft stress and fatigue calculations.

---

## Gear Material

- **Steel:** 18CrNiMo7-6 (DIN 1.6587)  
- **Heat treatment:** Case hardened  
  - Surface hardness: 56–60 HRC (≈ 600 HB)  
  - Core hardness: 38–42 HRC  
- **Ultimate tensile strength:** 1000–1300 MPa  
- **Yield strength:** 800–1000 MPa  
- **Bending fatigue strength, S_c:** 1650 MPa  
- **Contact fatigue strength, S_t:** 520 MPa  
- **Modulus of elasticity, E:** 205 GPa  
- **Poisson’s ratio, ν:** 0.29  
- **Manufacturing / quality:** Grade 2, quality number 10  

These values are used for AGMA-type bending and contact stress checks in
the gear design and verification.

---

## Other Components

Bearings, keys, retaining rings, and other standard components follow
catalog or manufacturer data and are not yet listed here in detail.
A more complete material and component list will be added in a later,
refined design stage.

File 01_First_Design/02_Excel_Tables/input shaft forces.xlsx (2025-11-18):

Input Reverse Gear |  |  |  |  |  | Input Gear 1
Components | Pitch Diameter [mm] | Position From Bearing A [mm] | Position From Bearing B [mm] | Ft [N] | Fr [N] | Components | Pitch Diameter [mm] | Position From Bearing A [mm] | Position From Bearing B [mm] | Ft [N] | Fr [N] | Components | Pitch Diameter [mm] | Position From Bearing A [mm] | Position From Bearing B [mm] | Ft [N] | Fr [N] | Fa [N]
Bearing A |  | 0 | 327 | 11353.99738 | -4132.517086 | Bearing A |  | 0 | 327 | 8609.623666 | -3133.646743 | Bearing B |  | 0 | 327
Reverse gear | 70 | 38.23 | 288.77 | -12857.14286 | 4679.617298 | Reverse gear | 70 | 38.23 | 288.77 | 0 | 0 | Reverse gear | 70 | 38.23 | 288.77 | -12857.14286 | 4679.617298 | 0
Gear 1 | 73.5 | 97.08 | 229.92 | 0 | 0 | Gear 1 | 73.5 | 97.08 | 229.92 | -12244.89796 | 4456.778379 | Gear 1 | 73.5 | 97.08 | 229.92 | -12244.89796 | 4456.778379 | 0
Gear 2 | 84 | 134 | 193 | 0 | 0 | Gear 2 | 84 | 134 | 193 | 0 | 0 | Gear 2 | 84 | 134 | 193 | -10714.28571 | 3899.681081 | 0
Gear 3 | 98 | 193 | 134 | 0 | 0 | Gear 3 | 98 | 193 | 134 | 0 | 0 | Gear 3 | 98 | 193 | 134 | -9183.673469 | 3342.583784 | 0
Gear 4 | 115.5 | 229.93 | 97.07 | 0 | 0 | Gear 4 | 115.5 | 229.93 | 97.07 | 0 | 0 | Gear 4 | 115.5 | 229.93 | 97.07 | -7792.207792 | 2836.131696 | 0
Gear 5 | 143.5 | 288.78 | 38.22 | 0 | 0 | Gear 5 | 143.5 | 288.78 | 38.22 | 0 | 0 | Gear 5 | 143.5 | 288.78 | 38.22 | -6271.777003 | 2282.740145 | 0
Bearing B |  | 327 | 0 | 1503.145478 | -547.1002119 | Bearing B |  | 327 | 0 | 3635.274293 | -1323.131636 | Bearing B |  | 327 | 0
Input Gear 2 |  |  |  |  |  | Input Gear 3
Components | Pitch Diameter [mm] | Position From Bearing A [mm] | Position From Bearing B [mm] | Ft [N] | Fr [N] | Components | Pitch Diameter [mm] | Position From Bearing A [mm] | Position From Bearing B [mm] | Ft [N] | Fr [N]
Bearing A |  | 0 | 327 | 6323.722149 | -2301.646632 | Bearing A |  | 0 | 327 | 3763.340198 | -1369.743814
Reverse gear | 70 | 38.23 | 288.77 | 0 | 0 | Reverse gear | 70 | 38.23 | 288.77 | 0 | 0
Gear 1 | 73.5 | 97.08 | 229.92 | 0 | 0 | Gear 1 | 73.5 | 97.08 | 229.92 | 0 | 0
Gear 2 | 84 | 134 | 193 | -10714.28571 | 3899.681081 | Gear 2 | 84 | 134 | 193 | 0 | 0
Gear 3 | 98 | 193 | 134 | 0 | 0 | Gear 3 | 98 | 193 | 134 | -9183.673469 | 3342.583784
Gear 4 | 115.5 | 229.93 | 97.07 | 0 | 0 | Gear 4 | 115.5 | 229.93 | 97.07 | 0 | 0
Gear 5 | 143.5 | 288.78 | 38.22 | 0 | 0 | Gear 5 | 143.5 | 288.78 | 38.22 | 0 | 0
Bearing B |  | 327 | 0 | 4390.563565 | -1598.034449 | Bearing B |  | 327 | 0 | 5420.333271 | -1972.83997
Input Gear 4 |  |  |  |  |  | Input Gear 5
Components | Pitch Diameter [mm] | Position From Bearing A [mm] | Position From Bearing B [mm] | Ft [N] | Fr [N] | Components | Pitch Diameter [mm] | Position From Bearing A [mm] | Position From Bearing B [mm] | Ft [N] | Fr [N]
Bearing A |  | 0 | 327 | 2313.118075 | -841.9061275 | Bearing A |  | 0 | 327 | 733.0498993 | -266.8083436
Reverse gear | 70 | 38.23 | 288.77 | 0 | 0 | Reverse gear | 70 | 38.23 | 288.77 | 0 | 0
Gear 1 | 73.5 | 97.08 | 229.92 | 0 | 0 | Gear 1 | 73.5 | 97.08 | 229.92 | 0 | 0
Gear 2 | 84 | 134 | 193 | 0 | 0 | Gear 2 | 84 | 134 | 193 | 0 | 0
Gear 3 | 98 | 193 | 134 | 0 | 0 | Gear 3 | 98 | 193 | 134 | 0 | 0
Gear 4 | 115.5 | 229.93 | 97.07 | -7792.207792 | 2836.131696 | Gear 4 | 115.5 | 229.93 | 97.07 | 0 | 0
Gear 5 | 143.5 | 288.78 | 38.22 | 0 | 0 | Gear 5 | 143.5 | 288.78 | 38.22 | -6271.777003 | 2282.740145
Bearing B |  | 327 | 0 | 5479.089718 | -1994.225568 | Bearing B |  | 327 | 0 | 5538.727104 | -2015.931802

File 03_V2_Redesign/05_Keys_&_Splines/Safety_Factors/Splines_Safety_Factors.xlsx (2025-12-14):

location | module | number of teeth | addendum | dedendum | length [mm] | material | yield strength Sy[MPa] | failure by crushing
input shaft gear 5 | 3 | 15 | 0.45*module | 0.55*module | 20 | 18CrNiMo7-6 | 820 | 6.642
output shaft gear 1 - reverse | 3 | 18 | 0.45*module | 0.65*module | 8 | 18CrNiMo7-6 | 785 | 1.5987
dog ring sleeve gear 2 - 3 | 3 | 25 | 0.45*module | 0.55*module | 8 | 18CrNiMo7-6 | 785 | 3.8424
dog ring sleeve gear 4 - 5 | 3 | 25 | 0.45*module | 0.55*module | 8 | 18CrNiMo7-6 | 785 | 3.8424
output shaft flange | 3 | 12 | 0.45*module | 0.65*module | 25 | AISI 4140 Q&T | 1140 | 3.2246

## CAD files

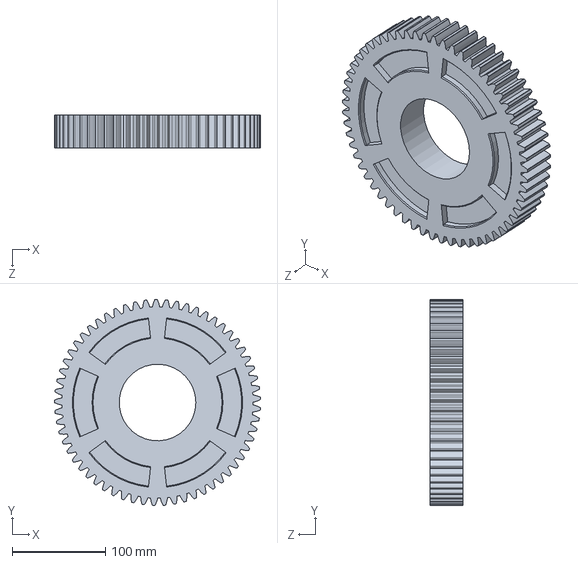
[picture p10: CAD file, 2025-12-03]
02_Architecture_V1_Review_and_Findings/02_Gearbox_Parts/Gear3_output.SLDPRT
220.5 x 220.5 x 35.0 mm

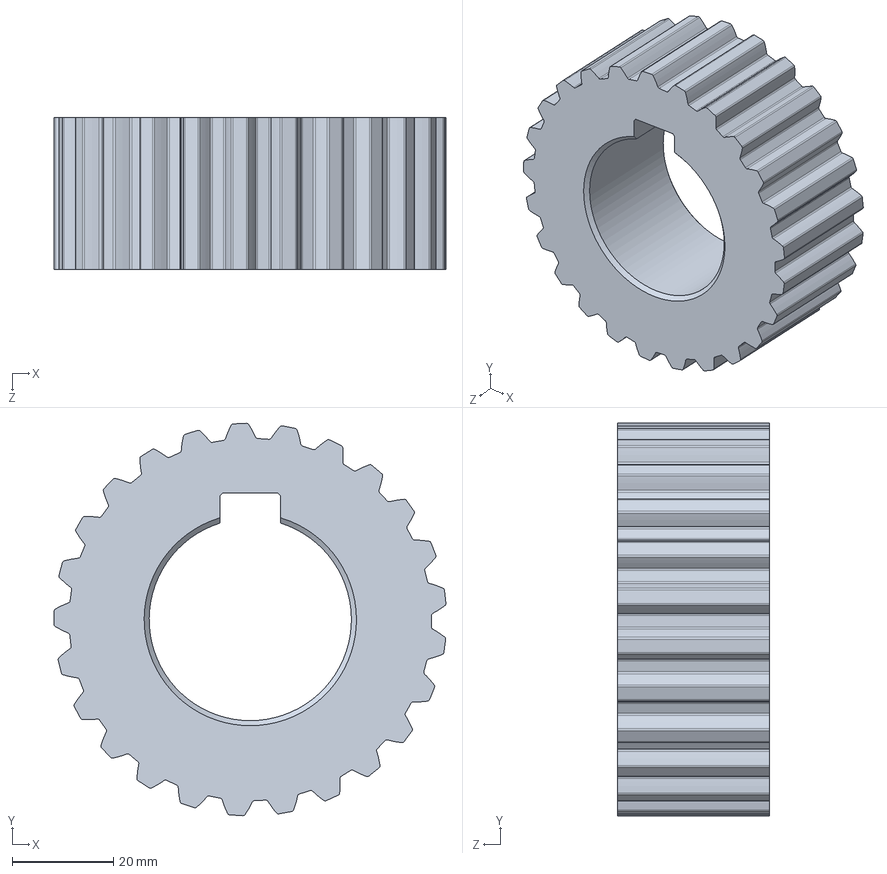
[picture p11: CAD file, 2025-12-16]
03_V2_Redesign/09_CAD/Solidworks/Solidworks_Parts/Dog_Ring_Sleeve_gear_4_5.SLDPRT
77.6 x 77.7 x 30.0 mm

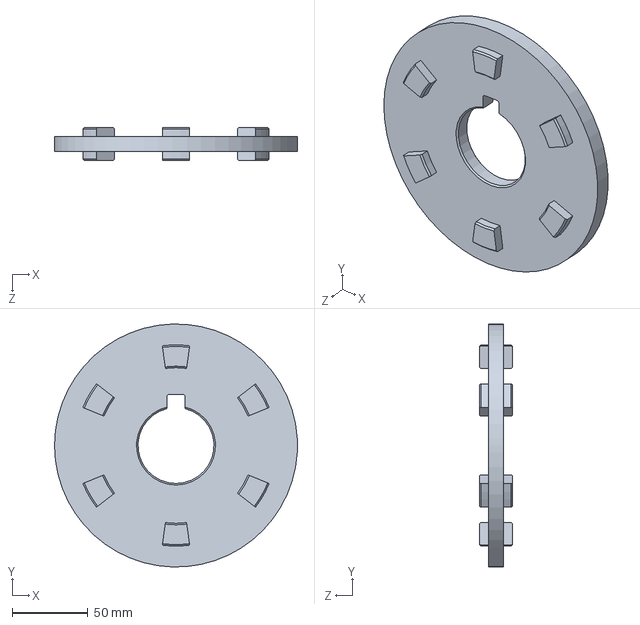
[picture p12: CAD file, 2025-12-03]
02_Architecture_V1_Review_and_Findings/02_Gearbox_Parts/Dog_ring_3.SLDPRT
160.0 x 159.9 x 22.0 mm

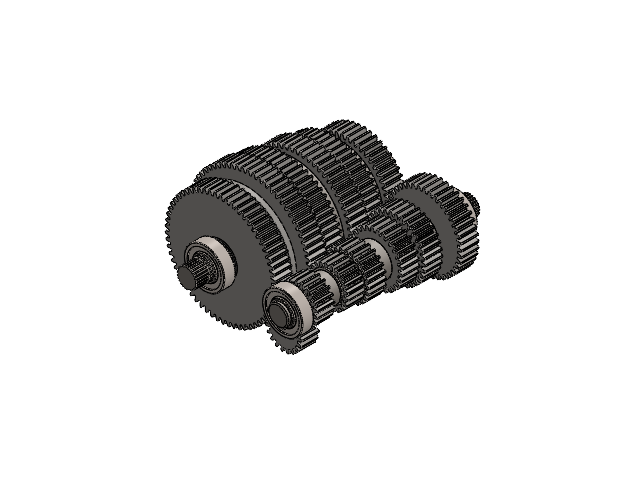
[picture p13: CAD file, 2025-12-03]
02_Architecture_V1_Review_and_Findings/03_Gearbox_Assembly/Gearbox_assembly_V1.SLDASM
input_shaft
Key_input x 6
ReverseGear_input
Part1^Gearbox_assembly_V1
Gear5_input
Gear1_input
Gear2_input
Gear3_input
Gear4_input
radial cylindrical roller bearing_skf x 4
basic external retaining ring_am x 8
output_shaft
Key_ouput x 3
NK68_35R+IR60x68x35Inner ring x 2
NK68_35R+IR60x68x35Outer ring x 2
NK68_35R+IR60x68x35 ring x 60
NK68_35R+IR60x68x35Cage x 2
NK55_35R+IR50x55x35Inner ring x 4
NK55_35R+IR50x55x35Outer ring x 4
NK55_35R+IR50x55x35 ring x 104
NK55_35R+IR50x55x35Cage x 4
Dog_ring_2
washer_input x 2
washer_output x 2
Gear2_output
idler_gear
ReverseGear_output
Dog_Sleeve_1
Dog_ring_1
Gear1_output
Gear3_output
Gear4_output
Gear5_output
Dog_ring_3

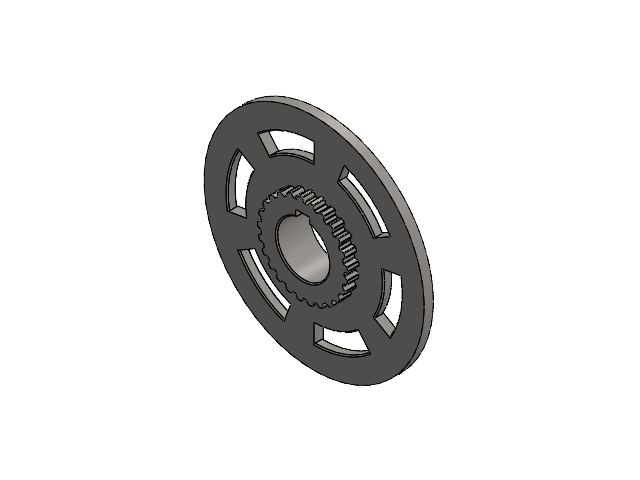
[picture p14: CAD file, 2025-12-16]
03_V2_Redesign/09_CAD/Solidworks/Solidworks_Assembly/Dog_Mechanism_2_&_3.SLDASM
Dog_Ring_2_&_3
Dog_Ring_Sleeve_gear_2_3

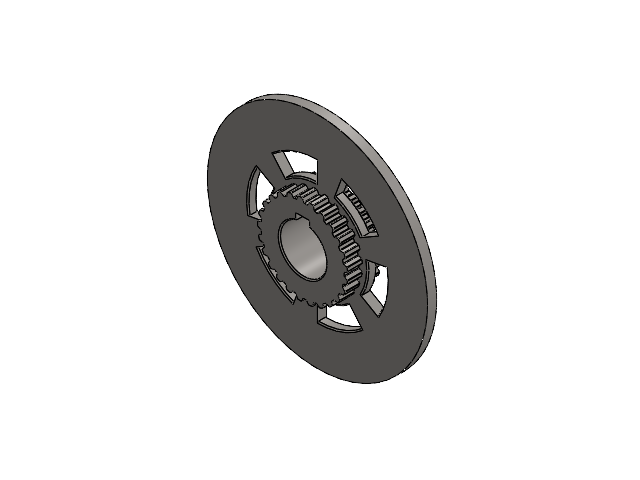
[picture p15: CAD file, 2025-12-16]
03_V2_Redesign/09_CAD/Solidworks/Solidworks_Assembly/Dog_Mechanism_4_&_5.SLDASM
Dog_Ring_4_&_5
Dog_Ring_Sleeve_gear_4_5

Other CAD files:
02_Architecture_V1_Review_and_Findings/02_Gearbox_Parts/Bearings/NK55_35R+IR50x55x35.sldasm
03_V2_Redesign/09_CAD/Solidworks/Bearings/Gear_2/SOLIDWORKS/NA5909.sldasm
02_Architecture_V1_Review_and_Findings/02_Gearbox_Parts/Bearings/NK68_35R+IR60x68x35.sldasm
03_V2_Redesign/09_CAD/Solidworks/Bearings/Gear_1/SOLIDWORKS/NA6910R.sldasm
03_V2_Redesign/09_CAD/Solidworks/Bearings/Gear_3/SOLIDWORKS/NK50_25RCT+IR45x50x25.sldasm
03_V2_Redesign/09_CAD/Solidworks/Bearings/Gear_5/SOLIDWORKS/NK45_20R+IR40x45x20.sldasm
03_V2_Redesign/09_CAD/Solidworks/Bearings/Gear_4/SOLIDWORKS/NA4908R.sldasm
03_V2_Redesign/09_CAD/Solidworks/Bearings/Gear_1/SOLIDWORKS/NA6910RInner ring.sldprt
03_V2_Redesign/09_CAD/Solidworks/Bearings/Gear_3/SOLIDWORKS/NK50_25RCT+IR45x50x25Cage.sldprt
03_V2_Redesign/09_CAD/Solidworks/Bearings/Gear_4/SOLIDWORKS/NA4908RInner ring.sldprt
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

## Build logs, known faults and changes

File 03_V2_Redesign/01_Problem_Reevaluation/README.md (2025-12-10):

## 1. Gears Specs
So first of all, we need to pose our gear ratios and check their conformity with desired car speed and torque at wheel. Another condition to check, is the center distance which all should respect.  

For this step, and after multiple checks and iterations, i got these gears setup:  

| gear | module | number of teeth - input gear | number of teeth - output gear |  ratio | center distance [mm] |
|---|---|---|---|---|---|
| gear 1  | 3 | 25 | 63 | 2.52 | 132 |
| gear 2  | 3 | 31 | 57 |  1.8387  | 132 |
| gear 3  | 3 | 37 | 51 |  1.378 | 132 |
| gear 4  | 3 | 41 | 47 |  1.1463  | 132 |
| gear 5  | 3 | 49 | 39 |  0.7959  | 132 |
| reverse | 2.5 | 31 | 68 |  2.1935  | 132 |
| idler | 2.5 | 23 | - | - | - |

Note: to meet the center distance requirement for the reverse gear, a special layout is made, this special layout is shown in "Reverse_Gear_Layout".
the idea of this layout is to not have the input, output and idler gears all aligned.

---

## 2. Speed and Torque at Wheel
Now that we have the number of teeth and the ratios of each gear, we can calculate the max speed of the car and the torque produced at wheel when each gear is engaged.  
For this step, i assumed the final gear ratio, the differential ratio, is at 4.8 and i call it i_final in next calculations which is considered normal for the purpose of this gearbox.  
And the tire we are using is 225/40 R18, so after calculations, the total tire diameter D = 637.2 mm = 0.6372 m; which will result in a tire circumference C_tire = 2 m  

n_wheel = n_engine/(i_gear * i_final);  
v = n_wheel * C_tire * 60/1000;  
T_wheel = T_in * i_gear * i_final * eff;  

> T_wheel: torque at wheel in [Nm]  
> T_in: torque from engine, which is constant at 450 Nm  
> i_gear: ratio of the engaged gear at the moment  
> i_final: differential ratio, which is assumed as 4.8  
> eff: differential efficiency, which is basically the torque transmission efficiency of the bevel gearset inside the differential, assumed as 0.9  
> n_wheel: wheel's rpm at a given engine rpm  
> n_engine: the engine's rpm at a given moment, since we are looking for max speed, it is going to be the engine's rev limit, i will assume that engine red line is at 6500 rpm  
> C_tire: car tire's circumference  

After numerical application, it got the following results:

|  gear  | speed [m/s] | torque at wheel [Nm] |
|---|---|---|
| gear 1 | 64.5429 | 4898.88 |
| gear 2 | 88.4582 | 3574.4328 |
| gear 3 | 118.032 | 2678.832 |
| gear 4 | 141.8896 | 2228.4072 |
| gear 5 | 204.3575 | 1547.2296 |

These values are acceptable for the purpose of the gearbox that is being made.  
The goal is not to get that top end speed, but rather focus on that mid range speed, torque and acceleration.

---

## 3. Bearings Check
Now that we have our gears specs, we can proceed to sketch our shafts.  
So for this step, i made a sketch of the shaft in order to be able to calculate the approximate diameters required and more importantly the bearings that will be installed.  
To get the needed size of bearings, we have to calculate C10.  
In order to be able to calculate C10, we need multiple values.  
desired life in hours;  
reliability;  
time fraction per gear;  
average rotation speed;  

 - For reliability we will go with 0.9 because we are not making an industrial gearbox that will be running for a long time.
 - the desired life of this gearbox is 40000 km, and assuming the average speed of the car is 60 km/h
	we will get a total number life in hours = 40000/60 = 667 hours
 - the average rotation speed of the engine is assumed at 4000 rpm, which is not low, but i will proceed with this number since the gearbox will be installed in a simple family car
 - time fraction per gear, we will assume a balanced mixed use between aggressive off road, rally-ish use and normal cruising. So time fraction per gear can be presented like the following:

| gear | time fraction |
|---|---|
| gear 1 | 0.1 |
| gear 2 | 0.2 |
| gear 3 | 0.2 |
| gear 4 | 0.25 |
| gear 5 | 0.25 |

I will be using cylindrical roller bearings.  
After calculation, we got a required C10 = 43.788 KN  
This C10 is for input shaft, we don't really need to calculate C10 on output shaft since 4 out of 5 gears are rotating at a speed less than that of the input, the rotation speed is divided by the ratio of each gear.  
No need to take reverse gear into consideration since it is rarely used in comparison with all other 5 gears, the time fraction will be at like 0.01 which is negligeable.  
After consulting the catalogues, i chose to use the following bearings:
- NUP 2206 ECP: bore diameter 30 mm - width 20 mm - load rating C = 55 KN  
- NUP 207 ECP: bore diameter 35 mm - width 17 mm - load rating C = 56 KN  
- NUP 208 ECP: bore diameter 40 mm - width 18 mm - load rating C = 62 KN  

And no this over design is not for nothing, it is for the shaft diameter requirement for later shaft fatigue analysis.

---

From this step forward, it will be hard to document as before since it is basically calculations everywhere. From shaft fatigue analysis to gears analysis all over to keys analysis.
I will show the outline of what will be done after that.

1. initial input and output shaft designs according to standards. A quick note: the output gears are gonna be installed on needle bearings to allow free movement and individual gear engagement
2. shaft fatigue analysis on the designs made: applying shaft fatigue failure criteria including Goodman, Gerber, Soderberg and ASME elliptic at different features of the shaft (grooves, shoulders, keyways and seats)
3. after checking and getting acceptable values for safety factors we move one to gears analysis: failure in bending and contact according to AGMA ways
4. after also getting acceptable values for gears, we can now jump to keys safety factors checking: failure by shear and by crushing
5. now comes the step of design the dog clutches: choosing the right number of dogs, the right thickness and width
6. last step is checking the keys and/or splines that are presented at the input and output of the gearbox which will hold the couplings. Basically the torque will be transmitted to the gearbox and from it by couplings

If all obtained values are acceptable, we can proceed to official drawings and simulation of the gearbox.

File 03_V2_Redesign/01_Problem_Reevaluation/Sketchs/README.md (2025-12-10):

This folder contains sketchs of input and output shaft, in addition to dog clutch components.  
These sketchs are not the final technical drawings, these sketchs are here to show the dimensions used in some calculation and the overall layout of some parts.  
For example, the dimensions on input shaft are used to draw moment diagrams which will be found in 02_Input_Shaft_Analysis folder.

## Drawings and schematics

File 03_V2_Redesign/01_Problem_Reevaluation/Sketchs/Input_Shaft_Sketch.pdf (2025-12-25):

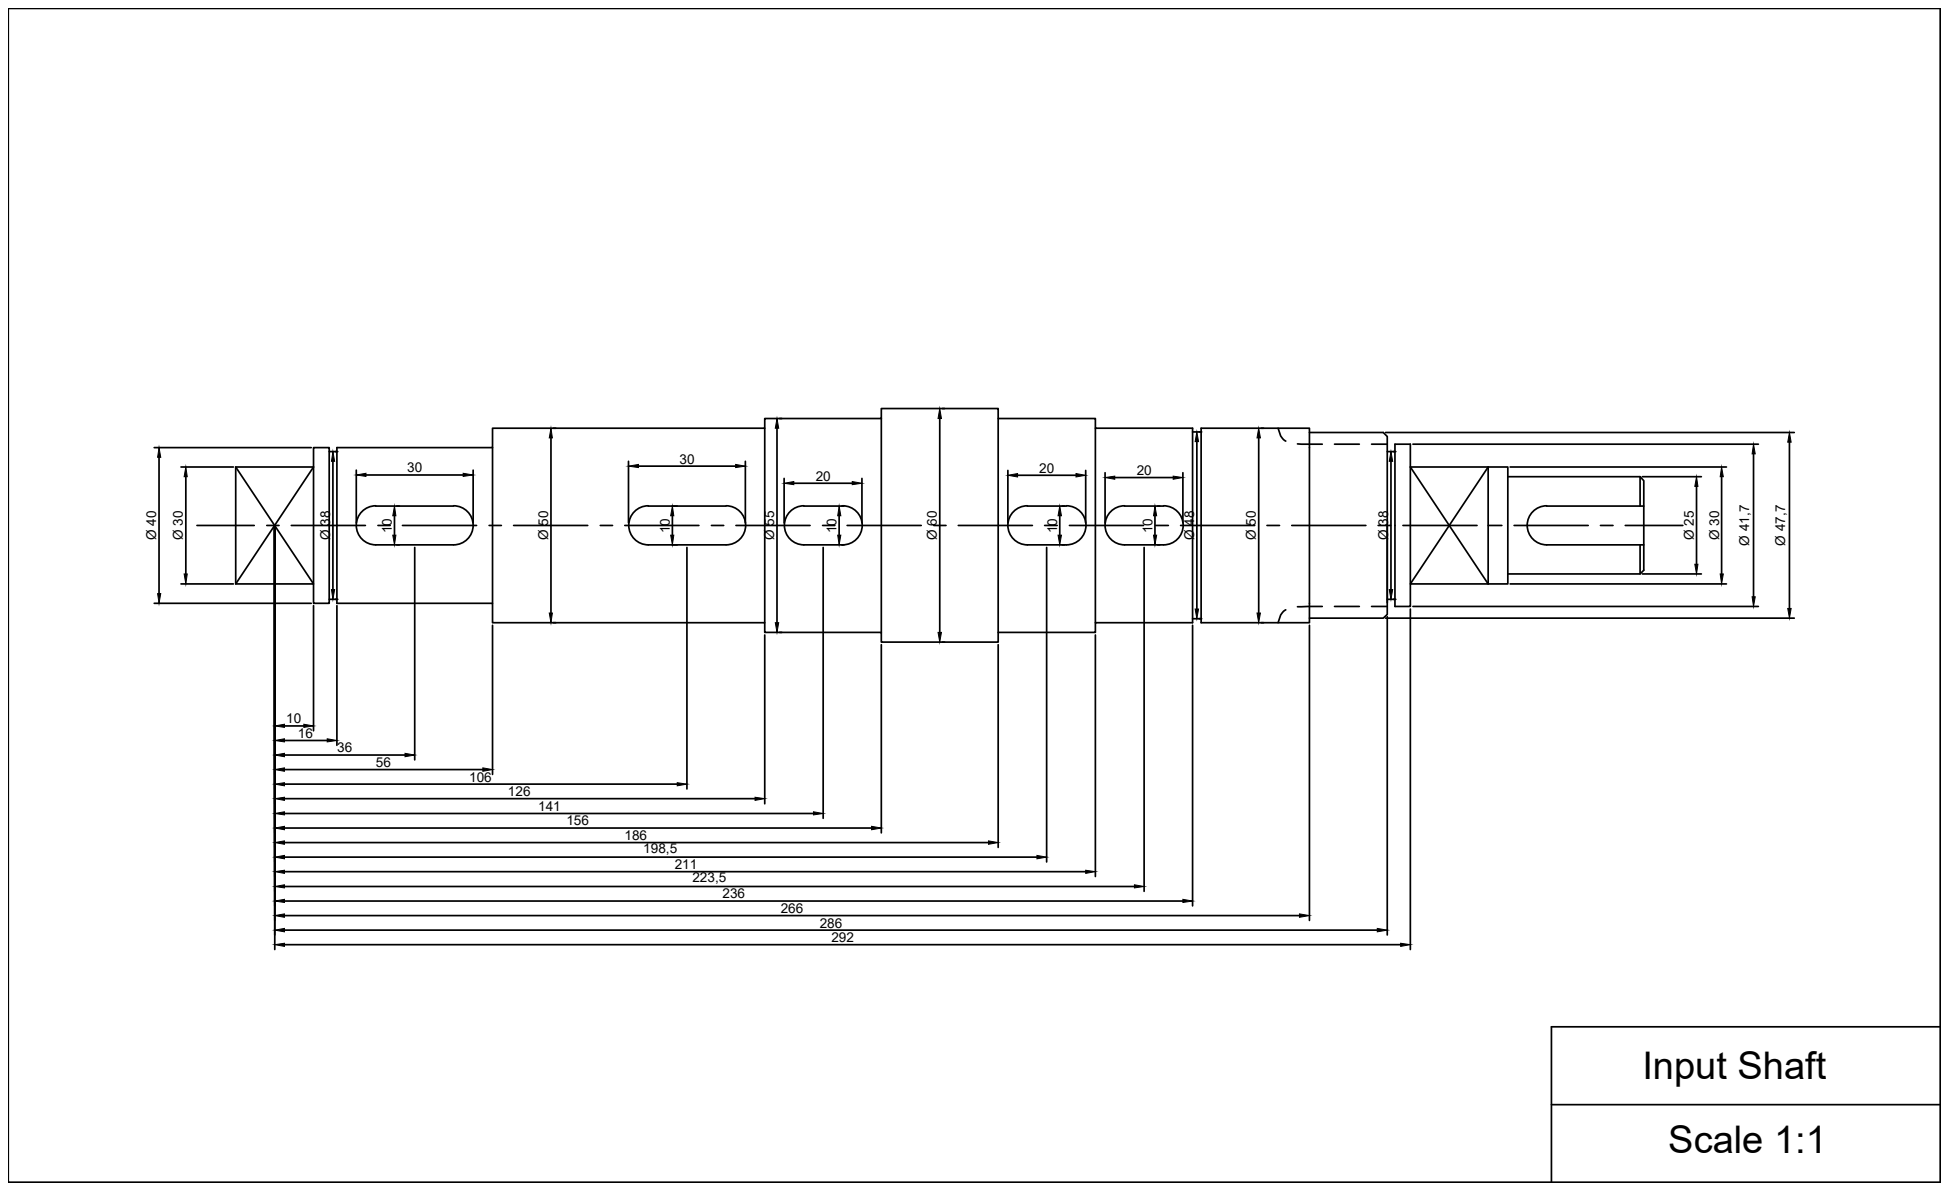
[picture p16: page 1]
Input Shaft; Scale 1:1

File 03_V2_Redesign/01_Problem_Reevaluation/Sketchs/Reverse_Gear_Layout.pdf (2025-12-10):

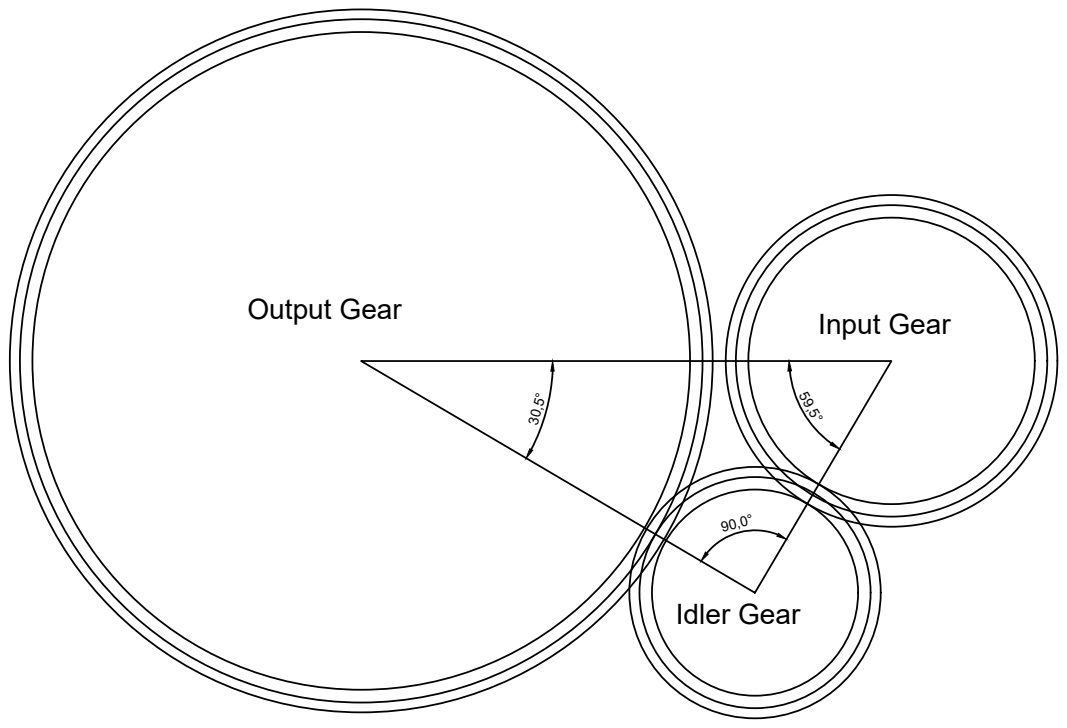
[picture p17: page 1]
Output Gear; Input Gear; Idler Gear

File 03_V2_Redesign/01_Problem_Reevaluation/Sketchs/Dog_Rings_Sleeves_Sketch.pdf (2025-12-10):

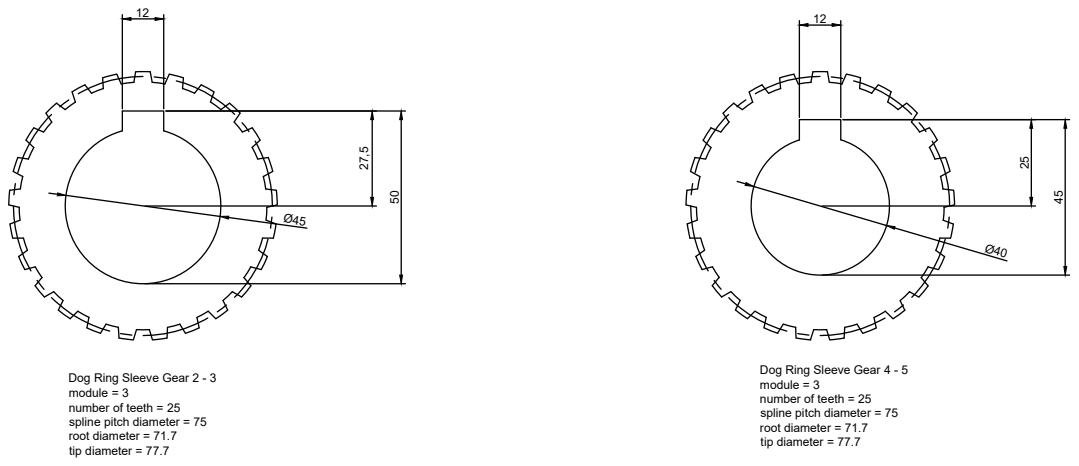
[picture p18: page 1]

Dog Ring Sleeve Gear 4 - 5
module = 3
number of teeth = 25
spline pitch diameter = 75
root diameter = 71.7
tip diameter = 77.7

Dog Ring Sleeve Gear 2 - 3

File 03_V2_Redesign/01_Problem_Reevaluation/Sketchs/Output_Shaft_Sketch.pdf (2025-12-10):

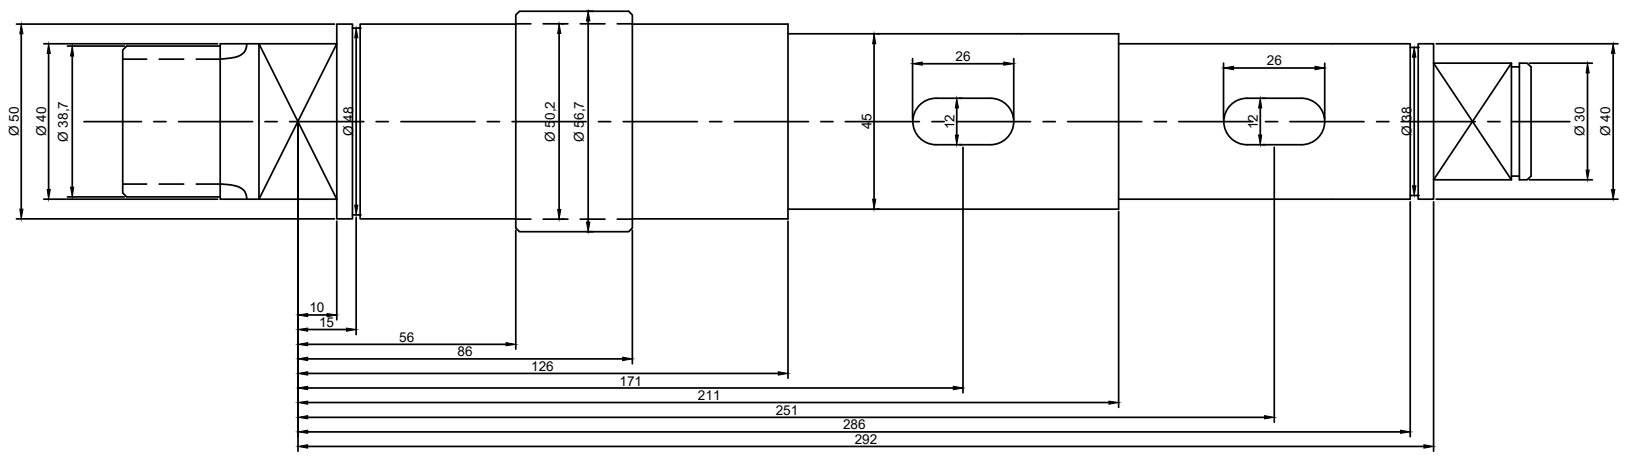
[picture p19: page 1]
Output Shaft; Scale 1:1

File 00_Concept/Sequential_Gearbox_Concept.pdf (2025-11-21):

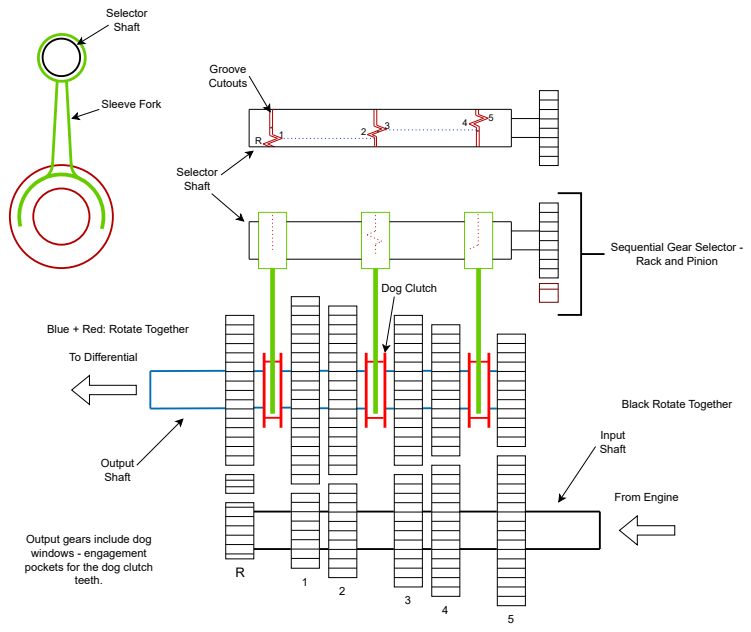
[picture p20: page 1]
To Differential; From Engine; Selector Shaft; Output Shaft; Input Shaft; Groove Cutouts; Dog Clutch; Sleeve Fork; teeth.

Sequential Gear Selector -
Rack and Pinion

Blue + Red: Rotate Together

Black Rotate Together

Output gears include dog
windows - engagement
pockets for the dog clutch

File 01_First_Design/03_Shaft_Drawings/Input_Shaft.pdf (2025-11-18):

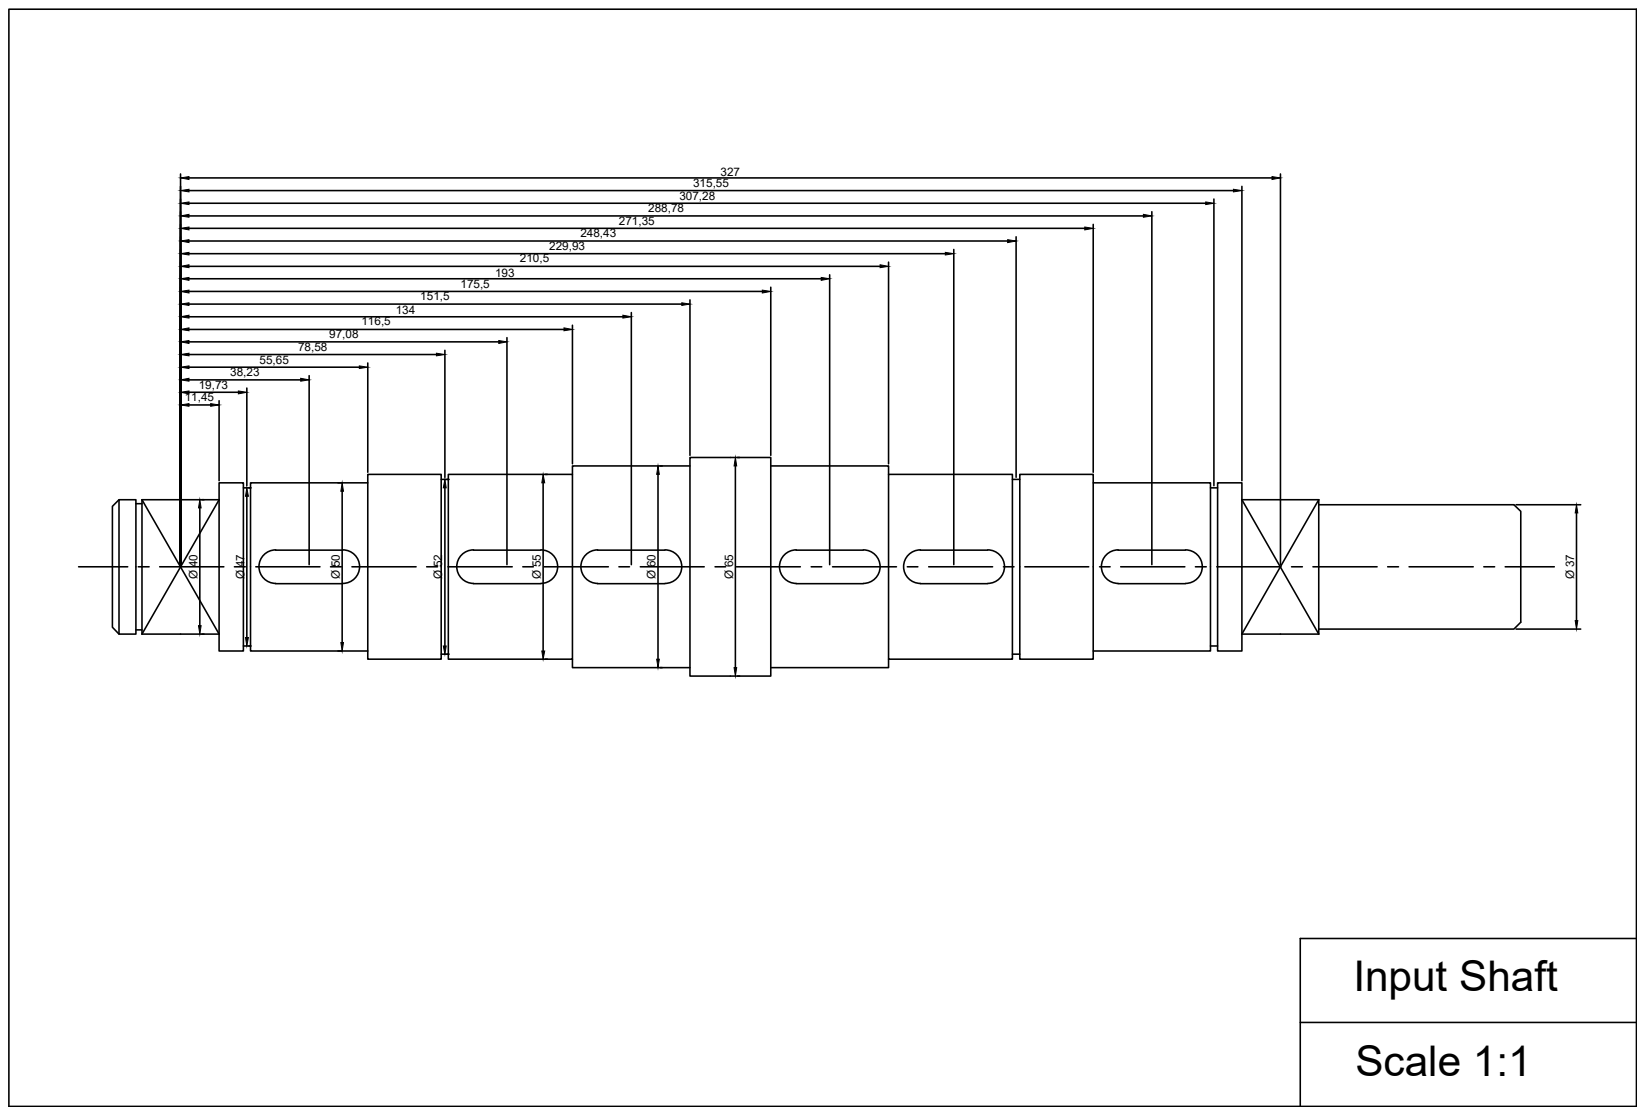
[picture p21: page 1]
Input Shaft; Scale 1:1

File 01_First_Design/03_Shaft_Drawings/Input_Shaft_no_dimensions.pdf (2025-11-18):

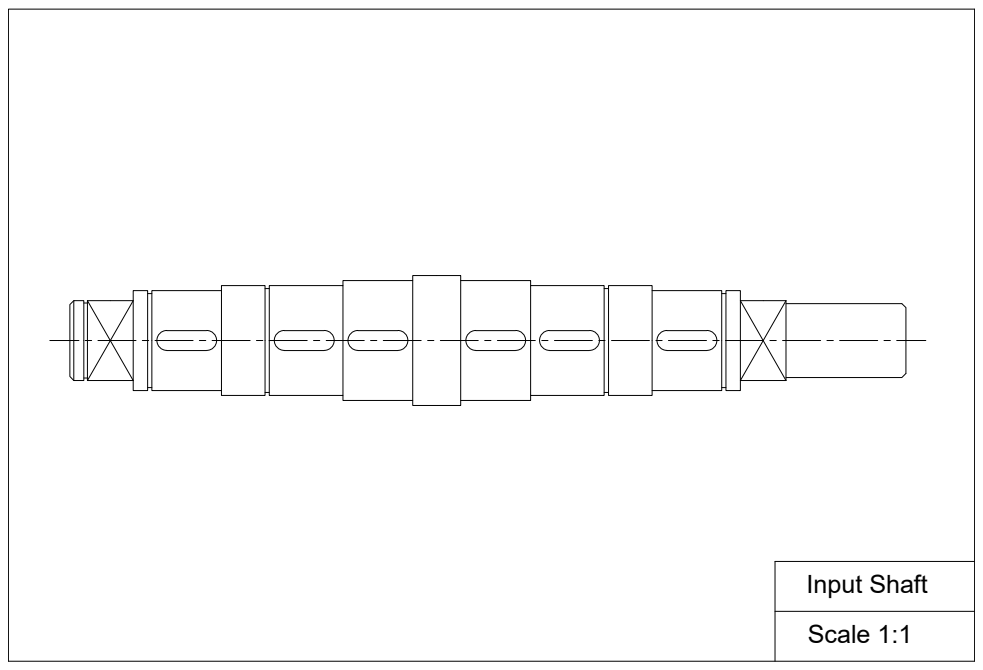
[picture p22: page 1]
Input Shaft; Scale 1:1

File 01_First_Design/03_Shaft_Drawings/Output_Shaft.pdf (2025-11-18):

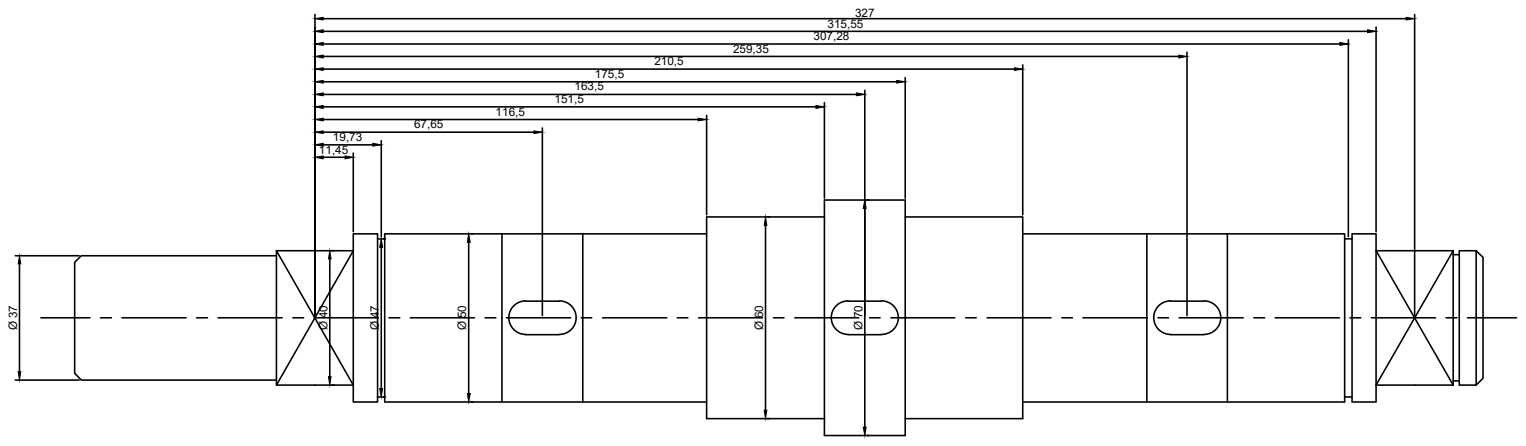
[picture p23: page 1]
Output Shaft; Scale 1:1
